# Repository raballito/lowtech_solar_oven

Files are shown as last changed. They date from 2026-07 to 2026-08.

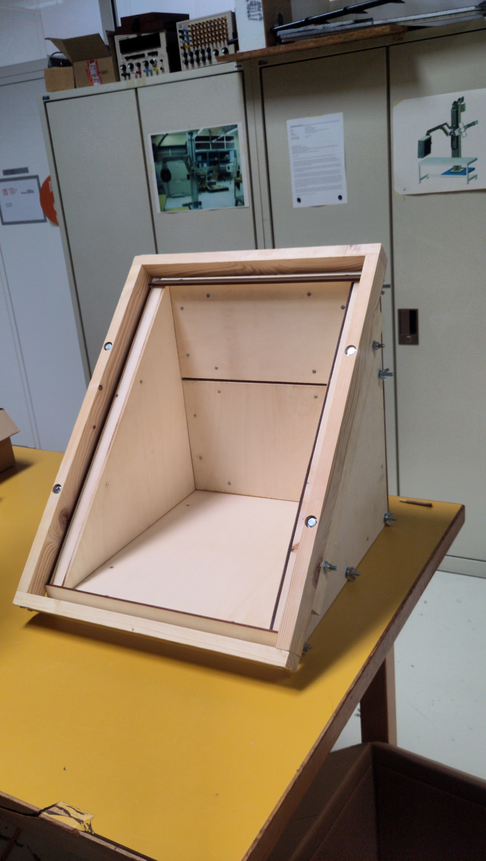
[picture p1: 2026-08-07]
IMG/IMG_20260701_142943_NR.jpg

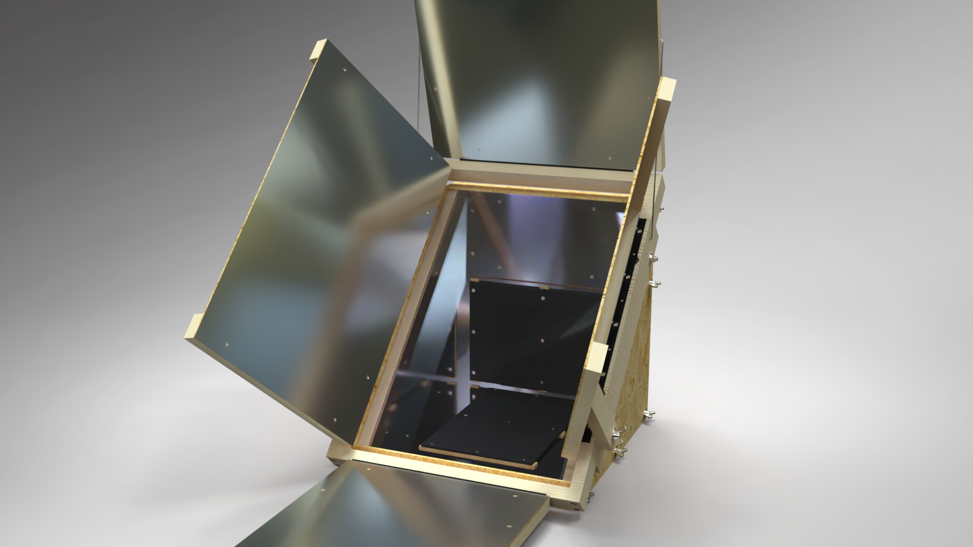
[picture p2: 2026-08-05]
Four Solaire Ouvert.png

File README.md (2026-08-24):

# Four solaire Low-tech

Ce répertoire contient tous les éléments afin de construire un four solaire low-tech DIY démontable.

Four Solaire Fermé

Ce four a été réalisé par Q.Raball dans le cadres du stage WINS 2026 de la HEIG-VD : https://heig-vd.ch/campus/ateliers-jeunes/wins/

Il a grandement été inspiré par le four Atominique dont la documentation, les plans, les instructions sont disponibles ici : https://four-atominique.retzien.fr/index.php?title=Accueil

Il reprend aussi certain élément intéressant du séchoir solaire de Mélanie Thomas disponible ici : [https://wiki.lowtechlab.org/wiki/S%C3%A9choir_solaire_d%C3%A9montable](https://wikifab.org/wiki/S%C3%A9choir_solaire_compact)

## Structure du Git
### Le dossier "CAO" contient les éléments suivants :
- Un fichier de prévisualisation du four au format EDrawings avec les deux configuration du four (ouvert/fermé). Le format EDrawings est très simple d'utilisation et pratique. Il est possible de bouger l'assemblage, de cacher certaines parties, de mettre en transparence certain éléments et permet de garder les configurations, les textures, la nomenclature, etc... Le logiciel est disponible gratuitement ici : https://www.edrawingsviewer.com/download-edrawings


- Dossier "STEP" avec toutes les pièces en 3D, au format STEP, ainsi que les fichiers d'assemblages final (Assemblage_Four_Deflecteur.STEP).
- Dossier "Solidworks" avec toutes les pièces en 3D, au format solidworks 2024, ainsi que les fichiers d'assemblages final (Assemblage_Four_Deflecteur.SLDASM).

### Le dossier "Docs" contient les éléments suivants : 
- Un dossier "BOM" avec la liste du matériel nécessaire à la fabrication (BOM), avec dimensions, quantités, prix, lien d'achat. Le classeur contient trois onglets: Le BOM par sous-assemblage, le BOM par type de composant et une liste de choix de miroirs pour l'intérieur et l'extérieur du four au cas où ceux dans les les autres ne sont plus disponibles à l'achat.


- Un dossier "Retour d'expérience" avec les différents problèmes rencontrés et les solutions mises en place.
- Un dossier "Choix des matériaux" avec les différents matériaux utilisés, les raisons des choix et les alternatives possibles.

### Le dossier "Plan" contient les éléments suivants : 
- Dossier "DXF" avec les fichiers de découpes afin de découper les panneaux de bois par technologie laser.
- Dossier "PDF" avec tous les plans des pièces avec assemblage, usinages et cotes


- Dossier "Solidworks" avec tous les fichiers de mises en plan au format Solidworks 2024

### Le dossier "Vids" contient les éléments suivants : 
- Les animations de montages pour les différents sous-assemblages du fours. Ne pas hésiter à ralentir la vidéo ou à mettre sur pause pour améliorer la compréhension.
Boite-ezgif com-video-to-gif-converter

## Liste des outils nécessaire à la fabrication et au montage
### Fabrication
- De quoi mesurer (règle, mètre déroulant) et écrire sur le bois (crayon de préférence).
- Une équerre à chapeau (DIN 875-2 idéalement), pour tracer des perpendiculaires et servir de guide à la découpe.
- Des serre-joints, ou pinces de bridage afin de maintenir deux éléments ensemble. Cela peut être pratique pour les positions des perçages si le plan n'est pas respecté à la lettre.
- Une scie (sauteuse) pour la découpe des tasseaux de bois et des tôles / miroirs. Un cutter peut être utile aussi.
- Une perceuse à colonne avec un jeu de mèches à bois. La plupart des trous sont Ø5, Ø9 ou Ø10. Les pré-trous pour les vis peuvent être fait avec une mèche de Ø2 (à adapter en fonction de la dureté du bois et de la taille des vis utilisées).
- Des mèches pour lamage droit / mèche à façonner / mèche-fraise plate de Ø20 ou Ø21 pour les têtes de vis et une de Ø13 ou Ø14 pour les écrous.
- Une mèche à tôle de Ø5 pour percer la tôle en acier. Une mèche standard peut se coincer et peut être dangereux.
- Eventuellement, une petite perceuse électroportative sur batterie peut être utile.

### Montage
- Tournevis / visseuse avec embout adapté aux vis utilisées.
- Clé à fourche taille 13 et clé à douille taille 13 pour la fixation des vis 6 pans dans les tasseaux.
- Des limes plates et rondes pour adapter les jeux entre les pièces et la taille des trous si nécessaire. Eventuellement une ponceuse peut être aussi utile.
- Des serre-joints, ou pinces de bridage afin de maintenir deux éléments ensemble. Cela peut être pratique pour assembler les tasseaux aux panneaux de bois.

Four Solaire Ouvert (3)

## Améliorations possibles / recommandées
- Afin de protéger les miroirs des rayures lorsqu'on les replies, les miroirs sont tapissés derrière la surface réfléchissante d'un tissus fin, et les charnières sont recouvertes d'un feutre. Des patins en caoutchouc ont été ajoutés sur le bas du cadre pour éviter que le grand miroir du dessus repose sur le bois directement.
- Remplacer les tringles en acier par un dispositif plus rigide. Au vu de la longueur des tringles prévues, elles ont tendances à fléchir. Pour éviter le fléchissement, il faut soit agrandir le diamètre de la tringle, soit raccourcir celle-ci. Sinon, il est aussi possible de changer le dispositif de réglage par une plaque en bois avec des secteurs. Un exemple de système de réglage est proposé à la fois dans les fichiers de découpes, les plans. Ne pas hésiter à adapter les formes, le nombre de trous à convenance.
- Il peut être judicieux d'ajouter un tablard sur le dessus afin de poser le plat à cuisiner pour ouvrir la porte. Par contre, si le dispositif est fixe, il devient plus compliqué de stocker le four à plat une fois démonté. Il est aussi plus compliqué de faire une four de protection adaptée avec un tel élément qui dépasse.
- Comme le four est lourd et encombrant, il peut être bien de le monter sur un chariot ou de rajouter des pieds à roulettes pour le déplacer. Un module supplémentaire sera inclus pour la version 2 du four.
- Le choix des matériaux pour les miroirs dépend fortement du budget à disposition. Plusieurs solutions sont possibles: plaques inox miroirs (lourd), panneaux de bois recouvert d'un film miroir (moins durable, plus simple), miroirs en plastiques (peut jaunir avec le temps), panneau Alucobond/Dibond (très cher et impossible d'avoir en petite quantité).
- Afin d'éviter au déflecteurs latéraux de se refermer avec le vent, il peut être judicieux de percer le cadre du déflecteur avec le support latéral servant à maintenir l'angle afin d'y mettre un clou. Cela permettra de bloquer la rotation du déflecteur.

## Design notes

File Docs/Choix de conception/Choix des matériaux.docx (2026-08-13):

# Choix des matériaux

## Enceinte du four

### Cahier des charges

Pour l'enceinte du four, les critères retenus sont :

- Absence de toxicité ;
- Résistance à la chaleur, avec une température de fonctionnement visée jusqu'à 180 °C ;
- Si possible, biocompatibilité / compatibilité alimentaire ;
- Faible masse ;
- Bonne durabilité ;
- Matériaux facilement disponibles et reproductibles ;
- Possibilité de remplacement ou de réparation.

### Structure en bois

Le contreplaqué de peuplier, notamment en 6 mm, a été envisagé pour les panneaux intérieurs et extérieurs de l'enceinte.

Ses avantages sont :

- Faible masse ;
- Bonne rigidité ;
- Coût raisonnable ;
- Disponibilité relativement importante, y compris en grande surface ;
- Bonne usinabilité et bonne découpe laser ;
- Matériau simple à remplacer ;
- Cohérent avec une démarche lowtech et open source.

Le point de vigilance principal est la colle utilisée dans le contreplaqué. Pour les éléments proches de l'intérieur chaud du four, il faut privilégier un panneau dont le fabricant peut fournir des informations sur les émissions, les colles et l'usage prévu. Le fait qu'un bois soit naturel ne signifie pas nécessairement que le panneau contreplaqué est automatiquement adapté à un environnement alimentaire ou à 180 °C.

Les panneaux ont été commandés en 800x500mm simplement car il s’agit de la taille maximum à disposition pour la machine de découpe laser disponible à l’école (Trotec Speedy 360).

Les tasseaux sont en sapin et de dimensions 24x48 et d’une longueur de 2m. Ces dimensions ont été choisies pour des raisons pratiques : facilement disponible dans n’importe quel magasin de bricolage, bonne rigidité globale et disponible en paquet de 10 (le nombre nécessaire pour la fabrication du four et des déflecteurs). 2m semble être le bon compromis, permettant un transport aisé en véhicule.

Aussi, aucune peinture doit être utilisé proche des aliments. L’intérieur est donc laissé brut. L’extérieur peut être discuté, mais comme le four est rangé en intérieur, l’extérieur sera laissé brut aussi.

### Isolation

Une isolation de l'ordre de 20mm a été envisagée. Les tasseaux utilisés faisant 24mm d’épaisseur, la différence de hauteur est compensée par l’ajout d’une plaque de 4mm coupé à la taille voulue à l’aide de la découpeuse laser.

Ses avantages sont :

- Faible conductivité thermique ;
- Bonne tenue en température ;
- Absence d'émissions indésirables lorsqu'il est chauffé ;
- Supporte l’humidité ;
- Faible masse ;
- Bonne disponibilité dans les commerces ;
- Possibilité de remplacement.

Le liège expansé constitue une piste particulièrement cohérente avec la philosophie du projet : matériau relativement accessible, biosourcé, léger et intéressant thermiquement. Il faut néanmoins vérifier la température maximale admissible du produit précis choisi et la nature éventuelle des liants.

Aussi, les panneaux de lièges se retrouvent dans la fabrication de fours solaires chez plein de fournisseurs (i.e SolarBrother).

### Revêtement intérieur réfléchissant

Le papier aluminium alimentaire a été utilisé dans le prototype, mais plusieurs limites ont été identifiées :

- Surface froissée ;
- Réflexion moins bonne qu'une surface métallique bien plane ;
- Fragilité ;
- Dégradation lors des manipulations ;
- Difficulté à le positionner et le faire tenir en place.

Une tôle d'aluminium mince (~0,8 mm) trouvée en magasin de bricolage constitue une solution beaucoup plus intéressante pour tapisser l'intérieur.

Ses avantages sont :

- Légère ;
- Assez rigide ;
- Facilement disponible ;
- Facile à nettoyer ;
- Meilleure planéité que le papier aluminium ;
- Facilement remplaçable.

Par contre, il faut faire attention à ne pas le rayer car il est compliqué de lui faire retrouver sa brillance. Après essais au papier de verre (jusqu’à P4000), l’aluminium est devenu mat. Il faut donc chercher à minimiser les rayures, mais sans pour autant s’acharner dessus.

## Déflecteurs extérieurs

### Cahier des charges

- Pas en contact avec les aliments ;
- Exposition directe au rayonnement solaire ;
- Bonne résistance aux UV ;
- Bonne résistance aux variations de température ;
- Bonne légereté ;
- Bonne planéité ;
- Bonne rigidité pour conserver leur géométrie ;

### Dibond / Alucobond miroir

Le Dibond miroir a été étudié comme solution très robuste.

Ses avantages sont :

- Excellente planéité ;
- Bonne rigidité ;
- Faible masse par rapport à un miroir en verre ;
- Bonne résistance extérieure ;
- Surface réfléchissante durable.

Mais le principal problème est le coût, de l'ordre de 100 CHF/m² dans les fournisseurs trouvés.

Pour un projet dont l'objectif est la reproductibilité et l'accessibilité, ce prix est difficile à justifier.

### Inox poli

L'acier inoxydable poli a également été envisagé.

Il présente une excellente durabilité et une très bonne résistance aux UV et aux intempéries, mais la masse devient rédhibitoire : pour les dimensions envisagées, on arrivait à environ 10 kg supplémentaires, sans parler du coût assez élevé de l’inox.

Cette solution a été écarté pour rester cohérent avec l’objectif d’être léger et peu cher.

### Contreplaqué + film miroir

C'est finalement une solution particulièrement intéressante :

Le contreplaqué fournit la rigidité mécanique et le film fournit la fonction optique.

Ses avantages sont :

- Très faible coût ;
- Faible masse globale;
- Fabrication simple ;
- Facilement réparable ;
- Matériau disponible localement ;
- Possibilité de remplacer uniquement la surface réfléchissante.

Le principal défaut est évidemment la durée de vie du film :

- UV ;
- Rayures ;
- Plis ;
- Résistance à l’humidité faible ;

Mais cela ne constitue pas nécessairement un problème de conception.

Un film qui doit être remplacé tous les 3–4 ans n'est pas nécessairement moins durable qu'un panneau miroir très coûteux qui dure beaucoup plus longtemps.

Si le panneau support reste intact et que seul le film est remplacé, on évite de jeter toute la pièce.

L'idéal est donc de concevoir le film pour être facilement démontable et remplaçable, plutôt que de le considérer comme une partie permanente du panneau.

### Miroir en polystyrène 2 mm

Des panneaux miroir en polystyrène de 2 mm ont été trouvés en magasin de bricolages

C'est une piste intéressante pour les déflecteurs car ils sont :

- Très légers ;
- Rigides ;
- Réfléchissants ;
- Relativement économiques ;
- Faciles à découper.

Par contre, les principaux points de vigilance sont :

- Sensibilité aux rayures ;
- Déformation thermique ;
- Vieillissement aux UV ;
- Tenue du matériau lorsqu'il est exposé directement au Soleil.

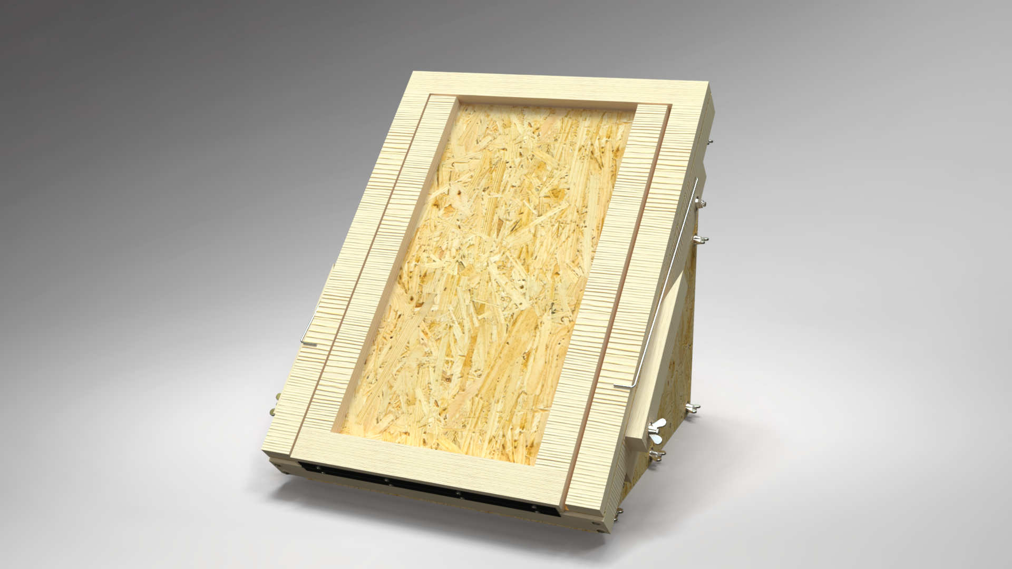
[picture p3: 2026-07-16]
Four Solaire Fermé.png

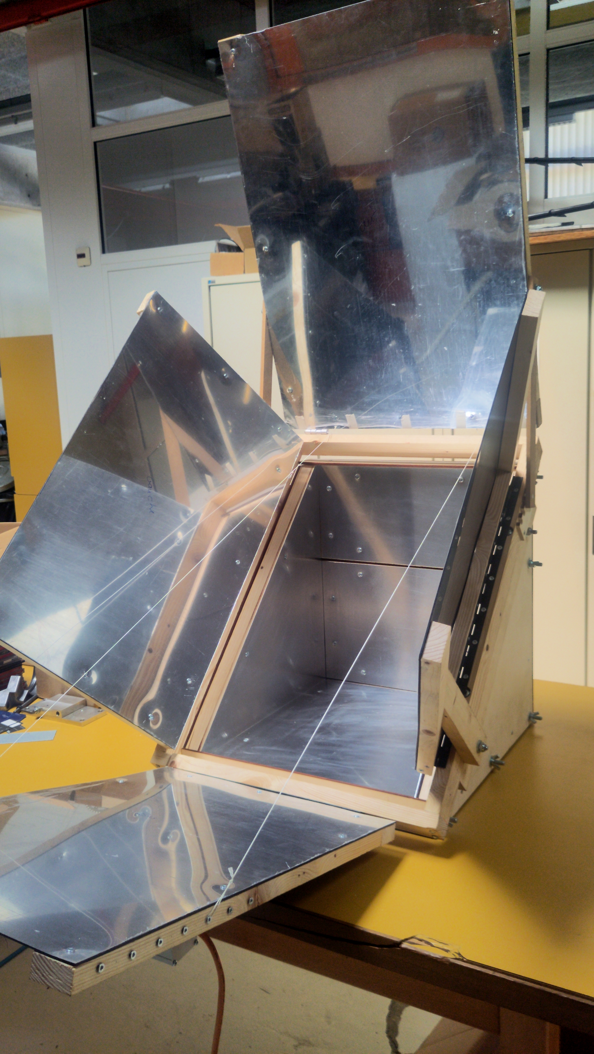
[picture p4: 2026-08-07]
IMG/IMG_20260807_123827_NR.jpg

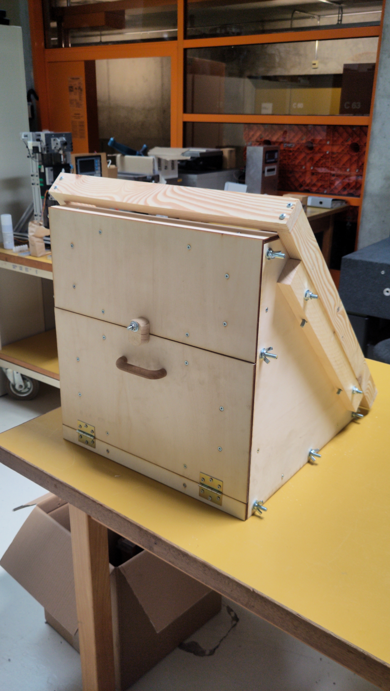
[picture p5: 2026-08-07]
IMG/IMG_20260701_143000_NR.jpg

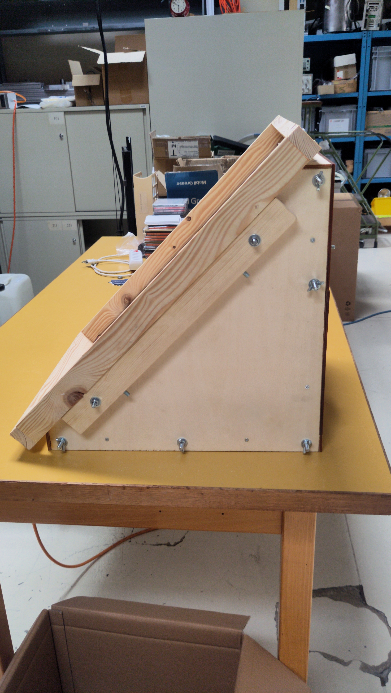
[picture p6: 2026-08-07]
IMG/IMG_20260701_143033_NR.jpg

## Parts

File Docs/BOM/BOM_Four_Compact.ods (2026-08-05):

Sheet: BOM_par_assamblage
No. ARTICLE | NUMERO DE PIECE | DESCRIPTION | Dimensions brutes | QTE | Prix Unitaire [CHF] | Prix Tot [CHF] | Opérations supplémentaires | Lien achat
1 | Assemblage_Four_Solaire | Assemblage Partie Boite | 510x505x516 | 1 | 194,52 |  | Assembler les panneaux à l'aide des écrous à oreilles
1.1 | Assemblage_Dessous | Assemblage de la partie du dessous | 500x468x55 | 1 | 44,34 | 44,34
1.1.1 | Base_Dessous | Plaque de base dessous | 500x400x6 | 2 | 5,40 | 10,80 | Trous pour passage de vis Ø5 (deux par côtés) | Panneau contreplaqué en peuplier Oecoplan A/B 6 mm Acheter chez JUMBO (https://www.jumbo.ch/fr/construction-renovation/bois/decoupe-du-bois/panneaux-contreplaques/panneau-contreplaque-en-peuplier-oecoplan-ab-6-mm/p/4706102) | 10.8CHF/panneau | 27CHF/m2
1.1.2 | Tasseau_304 | Tasseau dessous court | 304x48x24 | 4 | 0,36 | 1,46 |  | Tasseau brut Oecoplan | 2000 x 24 x 48 mm Acheter chez JUMBO (https://www.jumbo.ch/fr/construction-renovation/bois/bois-de-construction-bois-profile/lattes-de-toit/tasseau-brut-oecoplan--2000-x-24-x-48-mm/p/3851678)
1.1.3 | Tasseau_500_Dessous | Tasseau dessous long | 500x48x24 | 2 | 0,60 | 1,20 | Lamages de chaque côté Ø20 & Ø14 et trous passage de vis Ø8 | Tasseau brut Oecoplan | 2000 x 24 x 48 mm Acheter chez JUMBO (https://www.jumbo.ch/fr/construction-renovation/bois/bois-de-construction-bois-profile/lattes-de-toit/tasseau-brut-oecoplan--2000-x-24-x-48-mm/p/3851678) | 1.2CHF/m
1.1.4 | DIN EN 24015 - M8 x 90 | Vis tête hexagonale DIN EN 24015 - M8 x 90 | M8x90 | 6 | 1,17 | 7,00 | A fixer sur les tasseaux long | Ayce Vis à Tête Hexagonale | M8 Acheter chez JUMBO (https://www.jumbo.ch/fr/gros-outillage-atelier/petite-quincaillerie/vis/vis-a-metaux/ayce-vis-a-tete-hexagonale--m8/p/6930456) | 7CHF/6pièce
1.1.5 | DIN 315-M8-GT-C-C | Écrou à oreilles DIN 315 - M8 | M8 | 6 | 1,20 | 7,20 | Pour fixation des parois | Ayce Écrou à ailettes | M8 Acheter chez JUMBO (https://www.jumbo.ch/fr/gros-outillage-atelier/petite-quincaillerie/rondelles-plates-ecrous-gefundene-terminologie-eintraege4/ayce-ecrou-a-ailettes--m8/p/6930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) | 6CHF/5pièce
1.1.6 | Isolation_Dessous | Isolation en liège expensé | 303x102x20 | 3 | 0,80 | 2,41 | Idéalement, épaisseur de 24mm, sinon compléter avec panneau en bois de 4mm | Liège - Meige Matériaux (https://meige.ch/produits/isolation-et-etancheite/liege) | 26CHF/m2
1.1.7 | Cale_Plaque_Acier | Cale pour plaque acier | 250x20x4 | 3 | 0,11 | 0,32 | Trous de passage de vis Ø5 pour fixation sur dessous | Panneau contreplaqué en peuplier Oecoplan A/B 6 mm Acheter chez JUMBO (https://www.jumbo.ch/fr/construction-renovation/bois/decoupe-du-bois/panneaux-contreplaques/panneau-contreplaque-en-peuplier-oecoplan-ab-6-mm/p/4706102)
1.1.8 | Plaque_Acier | Plaque acier | 360x240x5 | 1 |  |  | A repeindre en noir avec peinture compatible avec la nourriture
1.1.9 | Planche_Fermeture | Planche de maintient de la vitre | 472x55x6 | 1 | 0,70 | 0,70 | Trous pour passage de vis Ø5 (3 pour fixation sur tasseau 304) | Panneau contreplaqué en peuplier Oecoplan A/B 6 mm Acheter chez JUMBO (https://www.jumbo.ch/fr/construction-renovation/bois/decoupe-du-bois/panneaux-contreplaques/panneau-contreplaque-en-peuplier-oecoplan-ab-6-mm/p/4706102)
1.1.10 | Planche_Derrière | Planche de maintient des charnière | 472x34x6 | 1 | 0,43 | 0,43 | Trous pour passage de vis Ø5 (2 pour fixation sur tasseau 304 + charnière (TBD)) | Panneau contreplaqué en peuplier Oecoplan A/B 6 mm Acheter chez JUMBO (https://www.jumbo.ch/fr/construction-renovation/bois/decoupe-du-bois/panneaux-contreplaques/panneau-contreplaque-en-peuplier-oecoplan-ab-6-mm/p/4706102)
1.1.11 | Charnière50x50 | Charnière Acier Noir | 50x50 | 2 | 2,25 | 4,50 | A fixer sur "Planche_Derrière" et à la porte (2x) | Hettich charnière de meuble | acier | noir | 50 mm (https://www.jumbo.ch/fr/gros-outillage-atelier/ferrures-accessoires/ferrures/charnieres-vivaneaux/hettich-charniere-de-meuble--acier--noir--50-mm/p/7491098) | 5.5CHF/2pièces
1.1.12 | Hexagon Nut ISO 4034 - M8 - C | Écrou hexagonal ISO 4034 - M8 | M8 | 6 | 0,30 | 1,80 |  | Ayce Écrou Hexagonal | M8 Acheter chez JUMBO (https://www.jumbo.ch/fr/gros-outillage-atelier/petite-quincaillerie/rondelles-plates-ecrous-gefundene-terminologie-eintraege4/ayce-ecrou-hexagonal--m8/p/6930078) | 3CHF/10pièce
1.1.13 | Complément_isolation_dessous | Panneau complémentaire à l'isolation | 303x102x4 | 3 | 0,65 | 1,95 | Laisser du jeu pour qu'elles soient facilement positionnable sur l'isolation | Panneau contreplaqué en peuplier Oecoplan A/B 4 mm Acheter chez JUMBO (https://www.jumbo.ch/fr/construction-renovation/bois/decoupe-du-bois/panneaux-contreplaques/panneau-contreplaque-en-peuplier-oecoplan-ab-4-mm/p/4706098) | 8.4CHF/panneau | 21CHF/m2
1.1.14 | Washer ISO 7093 - 8 | Rondelle ISO 7093 - 8 | Ø24x2 | 6 | 0,12 | 0,72
1.1.15 | Vis à bois Ø4,5x16 | Vis pour fixation des face devant et derrnière | Ø4.5x16 | 5 | 0,09 | 0,43 | Les vis doivent être plus courte pour ne pas poser problème | Ayce Vis à bois universelle à tête fraisée | 4 × 16 mm Acheter chez JUMBO (https://www.jumbo.ch/fr/gros-outillage-atelier/petite-quincaillerie/vis/vis-a-bois/ayce-vis-a-bois-universelle-a-tete-fraisee--4--16-mm/p/6928458) | 6CHF/70Pièces
1.1.16 | Vis à bois Ø4,5x20 | Vis pour fixations des panneaux bois | Ø4.5x20 | 20 | 0,12 | 2,40 | Attention à les décaler dessous-dessus | Ayce Vis à bois universelle à tête fraisée | 20 × 4.5 mm Acheter chez JUMBO (https://www.jumbo.ch/fr/gros-outillage-atelier/petite-quincaillerie/vis/vis-a-bois/ayce-vis-a-bois-universelle-a-tete-fraisee--20--45-mm/p/6929252) | 6CHF/50pièces
1.1.17 | Vis à bois Ø4,5x30 | Vis pour fixation de la plaque acier | Ø4.5x30 | 9 | 0,11 | 1,03 | Pour la fixation de la plaque acier. | Ayce Vis à bois universelle à tête fraisée | 4.5 × 30 mm Acheter chez JUMBO (https://www.jumbo.ch/fr/gros-outillage-atelier/petite-quincaillerie/vis/vis-a-bois/ayce-vis-a-bois-universelle-a-tete-fraisee--45--30-mm/p/6930359) | 8CHF/70pièces
1.2 | Assemblage_Parois | Assemblage des parois | 500x500x58 | 2 | 17,63 | 35,27 | Parois symétriques. Attention au montage. Grande plaques et tasseau suppl. à l'extérieur
1.2.1 | Base_Parois | Plaque de base parois | 500x500x6 | 2 | 3,38 | 6,75 | Attention, deux versions différentes. La grande plaque à l'extérieur avec trous suppl. sur la diagonale | Panneau contreplaqué en peuplier Oecoplan A/B 6 mm Acheter chez JUMBO (https://www.jumbo.ch/fr/construction-renovation/bois/decoupe-du-bois/panneaux-contreplaques/panneau-contreplaque-en-peuplier-oecoplan-ab-6-mm/p/4706102)
1.2.2 | Tasseau_500_Parois | Tasseau horizontal parois | 500x48x24 | 1 | 0,60 | 0,60 | Trous pour passage des vis M8 de fixation avec le dessous | Tasseau brut Oecoplan | 2000 x 24 x 48 mm Acheter chez JUMBO (https://www.jumbo.ch/fr/construction-renovation/bois/bois-de-construction-bois-profile/lattes-de-toit/tasseau-brut-oecoplan--2000-x-24-x-48-mm/p/3851678)
1.2.3 | Tasseau_Parois_Biais | Tasseau de biais parois | 639x48x24 | 1 | 0,77 | 0,77 | Couper les extrémités à 45°. Deux trous de passages de vis M8. Intérieur avec lamages suppl. | Tasseau brut Oecoplan | 2000 x 24 x 48 mm Acheter chez JUMBO (https://www.jumbo.ch/fr/construction-renovation/bois/bois-de-construction-bois-profile/lattes-de-toit/tasseau-brut-oecoplan--2000-x-24-x-48-mm/p/3851678)
1.2.4 | Tasseau_Parois_Ext | Tasseau Extérieur pour support déflecteurs | 540x48x24 | 1 | 0,65 | 0,65 | Deux trous Ø10 pour fixation du cadre du déflecteur.
1.2.5 | Tasseau_452_Parois | Tasseau verticale parois | 452x48x24 | 1 | 0,54 | 0,54 | Trous de passage des vis M8 de fixation avec le fond. Attention à la position des trous. | Tasseau brut Oecoplan | 2000 x 24 x 48 mm Acheter chez JUMBO (https://www.jumbo.ch/fr/construction-renovation/bois/bois-de-construction-bois-profile/lattes-de-toit/tasseau-brut-oecoplan--2000-x-24-x-48-mm/p/3851678)
1.2.6 | Isolation_Parois_Verticale | Isolation en liège expensé | 383x383x20 | 1 | 1,91 | 1,91 | Idéalement, épaisseur de 24mm, sinon compléter avec panneau en bois de 4mm. Couper le carré à 45° | Liège - Meige Matériaux (https://meige.ch/produits/isolation-et-etancheite/liege)
1.2.7 | Complément_isolation_parois | Panneau complémentaire à l'isolation | 383x383x4 | 1 | 1,54 | 1,54 | Laisser du jeu pour qu'elles soient facilement positionnable sur l'isolation | Panneau contreplaqué en peuplier Oecoplan A/B 4 mm Acheter chez JUMBO (https://www.jumbo.ch/fr/construction-renovation/bois/decoupe-du-bois/panneaux-contreplaques/panneau-contreplaque-en-peuplier-oecoplan-ab-4-mm/p/4706098)
1.2.8 | DIN EN 24015 - M8 x 60 | Vis tête hexagonale DIN EN 24015 - M8 x 60 | M8x60 | 2 | 1,00 | 2,00 | A fixer sur le tasseau de biais intérieur | Ayce Vis à Tête Hexagonale | M8 Acheter chez JUMBO (https://www.jumbo.ch/fr/gros-outillage-atelier/petite-quincaillerie/vis/vis-a-metaux/ayce-vis-a-tete-hexagonale--m8/p/6930585) | 6CHF/6pièces
1.2.9 | Washer ISO 7093 - 8 | Rondelle ISO 7093 - 8 | Ø24x2 | 2 | 0,12 | 0,24 |  | Ayce Rondelle | M8 Acheter chez JUMBO (https://www.jumbo.ch/fr/gros-outillage-atelier/petite-quincaillerie/rondelles-plates-ecrous-gefundene-terminologie-eintraege4/ayce-rondelle--m8/p/6928510) | 6CHF/50pièces
1.2.10 | ISO - 7040 - M8 - C | Écrou autofreiné hexagonal ISO 7040 - M8 | M8 | 2 | 0,60 | 1,20 | Pour fixation du tasseau extérieur sur parois. | Ayce Écrou de sécurité | SW13 Acheter chez JUMBO (https://www.jumbo.ch/fr/gros-outillage-atelier/petite-quincaillerie/rondelles-plates-ecrous-gefundene-terminologie-eintraege4/ayce-ecrou-de-securite--sw13/p/6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) | 6CHF/10pièces
1.2.11 | Vis à bois Ø4,5x20 | Vis pour fixations des panneaux bois | Ø4.5x20 | 12 | 0,12 | 1,44 | Attention à les décaler dessous-dessus. | Vis universelle à tête fraisée | 4.5 × 20 mm Acheter chez JUMBO (https://www.jumbo.ch/fr/gros-outillage-atelier/petite-quincaillerie/vis/vis-a-bois/vis-universelle-a-tete-fraisee--45--20-mm/p/6934638)
No. ARTICLE | NUMERO DE PIECE | DESCRIPTION | Dimensions brutes | QTE | Prix Unitaire [CHF] | Prix Tot [CHF] | Opérations supplémentaires | Lien achat
1.3 | Assemblage_Fond | Assemblage du fond | 472x205x60 | 1 | 25,71 | 25,71 | Attention au sens haut-bas.
1.3.1 | Base_Fond | Plaque de base du fond | 400x200x6 | 2 | 2,16 | 4,32 | Trous pour passage de vis Ø5 (deux par côtés) + 1 trou Ø9 pour vis de verrouillage de la porte. | Panneau contreplaqué en peuplier Oecoplan A/B 6 mm Acheter chez JUMBO (https://www.jumbo.ch/fr/construction-renovation/bois/decoupe-du-bois/panneaux-contreplaques/panneau-contreplaque-en-peuplier-oecoplan-ab-6-mm/p/4706102)
1.3.2 | Tasseau_200_Fond | Tasseau verticale fond | 200x48x24 | 2 | 0,24 | 0,48 | Lamages de chaque côté Ø20 & Ø14 et trous passage de vis Ø8 | Tasseau brut Oecoplan | 2000 x 24 x 48 mm Acheter chez JUMBO (https://www.jumbo.ch/fr/construction-renovation/bois/bois-de-construction-bois-profile/lattes-de-toit/tasseau-brut-oecoplan--2000-x-24-x-48-mm/p/3851678)
1.3.3 | Tasseau_304_Fond | Tasseau horizontal fond | 304x48x24 | 2 | 0,36 | 0,73 | Sur celui du bas, ajouter un trou de passage de vis Ø8 et lamage Ø14 | Tasseau brut Oecoplan | 2000 x 24 x 48 mm Acheter chez JUMBO (https://www.jumbo.ch/fr/construction-renovation/bois/bois-de-construction-bois-profile/lattes-de-toit/tasseau-brut-oecoplan--2000-x-24-x-48-mm/p/3851678)
1.3.4 | DIN EN 24015 - M8 x 90 | Vis tête hexagonale DIN EN 24015 - M8 x 90 | M8x90 | 4 | 1,17 | 4,67 |  | Ayce Vis à Tête Hexagonale | M8 Acheter chez JUMBO (https://www.jumbo.ch/fr/gros-outillage-atelier/petite-quincaillerie/vis/vis-a-metaux/ayce-vis-a-tete-hexagonale--m8/p/6930456)
1.3.5 | DIN 315-M8-GT-C-C | Écrou à oreilles DIN 315 - M8 | M8 | 4 | 1,20 | 4,80 | Pour fixation des parois | Ayce Écrou à ailettes | M8 Acheter chez JUMBO (https://www.jumbo.ch/fr/gros-outillage-atelier/petite-quincaillerie/rondelles-plates-ecrous-gefundene-terminologie-eintraege4/ayce-ecrou-a-ailettes--m8/p/6930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)
1.3.6 | Isolation_Fond | Isolation en liège expensé | 303x102x20 | 1 | 0,80 | 0,80 | Idéalement, épaisseur de 24mm, sinon compléter avec panneau en bois de 4mm | Liège - Meige Matériaux (https://meige.ch/produits/isolation-et-etancheite/liege)
1.3.7 | Planche_Fond_Grande | Planche Derrière Grande | 472x200x6 | 1 | 2,55 | 2,55 | Trous pour passage de vis Ø5 (deux par côtés) + 1 trou Ø9 pour vis de verrouillage de la porte. | Panneau contreplaqué en peuplier Oecoplan A/B 6 mm Acheter chez JUMBO (https://www.jumbo.ch/fr/construction-renovation/bois/decoupe-du-bois/panneaux-contreplaques/panneau-contreplaque-en-peuplier-oecoplan-ab-6-mm/p/4706102)
1.3.8 | Fixation_Porte | Système de fermeture de la porte | 60x48x24 | 1 | 0,07 | 0,07 | Arrondir les angles et un trou de passage de vis Ø9 | Tasseau brut Oecoplan | 2000 x 24 x 48 mm Acheter chez JUMBO (https://www.jumbo.ch/fr/construction-renovation/bois/bois-de-construction-bois-profile/lattes-de-toit/tasseau-brut-oecoplan--2000-x-24-x-48-mm/p/3851678)
1.3.9 | Planche_Fermeture | Planche_Fermeture (468x55) | 472x55x6 | 1 | 0,70 | 0,70 | Trous pour passage de vis Ø5 (3 pour fixation sur tasseau 304 du haut) | Panneau contreplaqué en peuplier Oecoplan A/B 6 mm Acheter chez JUMBO (https://www.jumbo.ch/fr/construction-renovation/bois/decoupe-du-bois/panneaux-contreplaques/panneau-contreplaque-en-peuplier-oecoplan-ab-6-mm/p/4706102)
1.3.10 | Hexagon Nut ISO 4034 - M8 - C | Écrou hexagonal ISO 4034 - M8 | M8 | 4 | 0,30 | 1,20 |  | Ayce Écrou Hexagonal | M8 Acheter chez JUMBO (https://www.jumbo.ch/fr/gros-outillage-atelier/petite-quincaillerie/rondelles-plates-ecrous-gefundene-terminologie-eintraege4/ayce-ecrou-hexagonal--m8/p/6930078)
1.3.11 | Complément_isolation_fond | Panneau complémentaire à l'isolation | 303x102x4 | 1 | 0,65 | 0,65 | Laisser du jeu pour qu'elles soient facilement positionnable sur l'isolation | Panneau contreplaqué en peuplier Oecoplan A/B 4 mm Acheter chez JUMBO (https://www.jumbo.ch/fr/construction-renovation/bois/decoupe-du-bois/panneaux-contreplaques/panneau-contreplaque-en-peuplier-oecoplan-ab-4-mm/p/4706098)
1.3.12 | DIN EN 24015 - M8 x 60 | Vis tête hexagonale DIN EN 24015 - M8 x 60 | M8x60 | 1 | 1,00 | 1,00 | Pour fixation du tasseau de fermeture de la porte | Ayce Vis à Tête Hexagonale | M8 Acheter chez JUMBO (https://www.jumbo.ch/fr/gros-outillage-atelier/petite-quincaillerie/vis/vis-a-metaux/ayce-vis-a-tete-hexagonale--m8/p/6930585)
1.3.13 | Washer ISO 7093 - 8 | Rondelle ISO 7093 - 8 | Ø24x2 | 1 | 0,12 | 0,12 |  | Ayce Rondelle | M8 Acheter chez JUMBO (https://www.jumbo.ch/fr/gros-outillage-atelier/petite-quincaillerie/rondelles-plates-ecrous-gefundene-terminologie-eintraege4/ayce-rondelle--m8/p/6928510)
1.3.14 | DIN EN ISO 7040 - M8 - C | Écrou autofreiné hexagonal ISO 7040 - M8 | M8 | 1 | 0,60 | 0,60 |  | Ayce Écrou de sécurité | SW13 Acheter chez JUMBO (https://www.jumbo.ch/fr/gros-outillage-atelier/petite-quincaillerie/rondelles-plates-ecrous-gefundene-terminologie-eintraege4/ayce-ecrou-de-securite--sw13/p/6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)
1.3.15 | Washer ISO 7093 - 8 | Rondelle ISO 7093 - 8 | Ø24x2 | 4 | 0,12 | 0,48
1.3.16 | Vis à bois Ø4,5x16 | Vis pour fixation des face devant et derrnière | Ø4.5x16 | 3 | 0,09 | 0,26 | Les vis doivent être plus courte pour ne pas poser problème | Ayce Vis à bois universelle à tête fraisée | 4 × 16 mm Acheter chez JUMBO (https://www.jumbo.ch/fr/gros-outillage-atelier/petite-quincaillerie/vis/vis-a-bois/ayce-vis-a-bois-universelle-a-tete-fraisee--4--16-mm/p/6928458)
1.3.17 | Vis à bois Ø4,5x20 | Vis pour fixations des panneaux bois | Ø4.5x20 | 19 | 0,12 | 2,28 | Attention à les décaler dessous-dessus. | Vis universelle à tête fraisée | 4.5 × 20 mm Acheter chez JUMBO (https://www.jumbo.ch/fr/gros-outillage-atelier/petite-quincaillerie/vis/vis-a-bois/vis-universelle-a-tete-fraisee--45--20-mm/p/6934638)
1.4 | Assemblage_Porte | Assemblage de la porte | 472x270x50 | 1 | 22,20 | 22,20
1.4.1 | Planche_Porte_Derrière_Grande | Grande plaque de la porte | 472x270x6 | 1 | 3,44 | 3,44 | Trous pour passage de vis Ø5 (deux par côté + charnière (TBD)) | Panneau contreplaqué en peuplier Oecoplan A/B 6 mm Acheter chez JUMBO (https://www.jumbo.ch/fr/construction-renovation/bois/decoupe-du-bois/panneaux-contreplaques/panneau-contreplaque-en-peuplier-oecoplan-ab-6-mm/p/4706102)
1.4.2 | Base_Porte | Petites plaque de base de la porte | 400x260x6 | 2 | 2,81 | 5,62 | Trous pour passage de vis Ø5 (deux par côté + plaque acier (TBD)) | Panneau contreplaqué en peuplier Oecoplan A/B 6 mm Acheter chez JUMBO (https://www.jumbo.ch/fr/construction-renovation/bois/decoupe-du-bois/panneaux-contreplaques/panneau-contreplaque-en-peuplier-oecoplan-ab-6-mm/p/4706102)
1.4.3 | Tasseau_260 | Tasseau vertical porte | 260x48x24 | 2 | 0,31 | 0,62 |  | Tasseau brut Oecoplan | 2000 x 24 x 48 mm Acheter chez JUMBO (https://www.jumbo.ch/fr/construction-renovation/bois/bois-de-construction-bois-profile/lattes-de-toit/tasseau-brut-oecoplan--2000-x-24-x-48-mm/p/3851678)
1.4.4 | Tasseau_304 | Tasseau horizontal porte | 304x48x24 | 2 | 0,36 | 0,73 |  | Tasseau brut Oecoplan | 2000 x 24 x 48 mm Acheter chez JUMBO (https://www.jumbo.ch/fr/construction-renovation/bois/bois-de-construction-bois-profile/lattes-de-toit/tasseau-brut-oecoplan--2000-x-24-x-48-mm/p/3851678)
1.4.5 | Isolation_Porte | Isolation en liège expensé | 303x163x20 | 1 | 1,28 | 1,28 | Idéalement, épaisseur de 24mm, sinon compléter avec panneau en bois de 4mm | Liège - Meige Matériaux (https://meige.ch/produits/isolation-et-etancheite/liege)
1.4.6 | Complément_isolation_porte | Panneau complémentaire à l'isolation | 303x163x4 | 1 | 1,04 | 1,04 | Laisser du jeu pour qu'elles soient facilement positionnable sur l'isolation | Panneau contreplaqué en peuplier Oecoplan A/B 4 mm Acheter chez JUMBO (https://www.jumbo.ch/fr/construction-renovation/bois/decoupe-du-bois/panneaux-contreplaques/panneau-contreplaque-en-peuplier-oecoplan-ab-4-mm/p/4706098)
1.4.7 | Plaque_Acier | Plaque acier | 360x240x5 | 1 |  |  | Doit être percée et maintenue à la porte, séparée par les cales
1.4.8 | Cale_Plaque_Acier_Porte | Cale pour plaque acier | 250x20x4 | 3 | 0,11 | 0,32 | Trous de passage de vis Ø5 pour fixation sur porte | Panneau contreplaqué en peuplier Oecoplan A/B 4 mm Acheter chez JUMBO (https://www.jumbo.ch/fr/construction-renovation/bois/decoupe-du-bois/panneaux-contreplaques/panneau-contreplaque-en-peuplier-oecoplan-ab-4-mm/p/4706098)
1.4.9 | Poignée_Porte | Poignée en bois pour porte | 107*14*29 | 1 | 6,20 | 6,20 | TBD | Siro Poignée de meuble en Érable Brut | 107 × 14 × 29 mm Acheter chez JUMBO (https://www.jumbo.ch/fr/gros-outillage-atelier/ferrures-accessoires/ferrures/boutons-poignees/siro-poignee-de-meuble-en-erable-brut--107--14--29-mm/p/3444144) | 6.2CHF/pièce
1.4.10 | Vis à bois Ø4,5x20 | Vis pour fixations des panneaux bois | Ø4.5x20 | 16 | 0,12 | 1,92 | Attention à les décaler dessous-dessus. | Vis universelle à tête fraisée | 4.5 × 20 mm Acheter chez JUMBO (https://www.jumbo.ch/fr/gros-outillage-atelier/petite-quincaillerie/vis/vis-a-bois/vis-universelle-a-tete-fraisee--45--20-mm/p/6934638)
1.4.11 | Vis à bois Ø4,5x30 | Vis pour fixation de la plaque acier | Ø4.5x30 | 9 | 0,11 | 1,03 | Pour la fixation de la plaque acier. | Ayce Vis à bois universelle à tête fraisée | 4.5 × 30 mm Acheter chez JUMBO (https://www.jumbo.ch/fr/gros-outillage-atelier/petite-quincaillerie/vis/vis-a-bois/ayce-vis-a-bois-universelle-a-tete-fraisee--45--30-mm/p/6930359)
1.5 | Tôle aluminium fine | Tôle alu miroir pour intérieur du four | 600x1000x0.8 | 1 | 42,00 | 42,00 | A découper selon les plans | Alfer Tôle lisse en Aluminium | 1000 × 600 × 0.8 mm Acheter chez JUMBO (https://www.jumbo.ch/fr/gros-outillage-atelier/ferrures-accessoires/profils/profiles-en-aluminium/alfer-tole-lisse-en-aluminium--1000--600--08-mm/p/4151895)
1.6 | Vitre | Vitre 4mm | 631x458x4 | 1 | 25,00 | 25,00 | Ajuster le jeu entre la plaque du haut et la vitre avec un morceau de tissus / liège (max 1mm à compenser) | vitrerie en ligne (https://vitreenligne.ch/fr/verre-transparent-/441-verre-float-4-mm-clair-verre-float-4-mm-clair-accueil-chf-1400.html)
No. ARTICLE | NUMERO DE PIECE | DESCRIPTION | Dimensions brutes | QTE | Prix Unitaire [CHF] | Prix Tot [CHF] | Opérations supplémentaires | Lien achat
2 | Assemblage_Déflecteurs | Assemblage Partie Déflecteurs | 728x566x80 | 1 | 66,96
2.1 | Cadre déflecteurs | Cadre support déflecteurs | 728x566x48 | 1
2.1.1 | Tasseau_518 | Tasseau Cadre Déflecteurs Court | 518x48x24 | 2 | 0,62 | 1,24 | 2x2 trous Ø5 aux extrémités pour former le cadre du déflecteurs | Tasseau brut Oecoplan | 2000 x 24 x 48 mm Acheter chez JUMBO (https://www.jumbo.ch/fr/construction-renovation/bois/bois-de-construction-bois-profile/lattes-de-toit/tasseau-brut-oecoplan--2000-x-24-x-48-mm/p/3851678)
2.1.2 | Tasseau_680 | Tasseau Cadre Déflecteurs Long | 680x48x24 | 2 | 0,82 | 1,63 | Faire 2x2 prétrous Ø3,5 pour assemblage cadre du déflecteurs. Lamages pour vis M8 dessus dessous et coté int. | Tasseau brut Oecoplan | 2000 x 24 x 48 mm Acheter chez JUMBO (https://www.jumbo.ch/fr/construction-renovation/bois/bois-de-construction-bois-profile/lattes-de-toit/tasseau-brut-oecoplan--2000-x-24-x-48-mm/p/3851678)
2.1.3 | Vis à bois Ø4.5 x 50 | Vis à bois Ø4.5 x 50 | Ø4.5x50 | 8 | 0,18 | 1,44 | Pour fixation du cadre
2.2 | Assemblage_Déflecteur_Gauche | Panneau déflecteur gauche | 678x435x28 | 1 | 12,36 | 12,36
2.2.1 | Miroir_Déflecteur_Gauche | Panneau miroir gauche | 678x435x2 | 1 | 10,62 | 10,62 | Idéalement, prendre de l'aluminium poli miroir, ou panneau bois 4mm avec film miroir. | Miroir en Polystyrène | 100 × 200 cm Acheter chez JUMBO (https://www.jumbo.ch/fr/construction-renovation/verre-verre-synthetique/verre-synthetique/miroir-en-polystyrene--100--200-cm/p/3374634)
2.2.2 | Tasseau_435 | Tasseau déflecteur gauche court | 435x48x24 | 2 | 0,52 | 1,04 |  | Tasseau brut Oecoplan | 2000 x 24 x 48 mm Acheter chez JUMBO (https://www.jumbo.ch/fr/construction-renovation/bois/bois-de-construction-bois-profile/lattes-de-toit/tasseau-brut-oecoplan--2000-x-24-x-48-mm/p/3851678)
2.2.3 | Tasseau_582 | Tasseau déflecteur gauche long | 582x48x24 | 1 | 0,70 | 0,70 |  | Tasseau brut Oecoplan | 2000 x 24 x 48 mm Acheter chez JUMBO (https://www.jumbo.ch/fr/construction-renovation/bois/bois-de-construction-bois-profile/lattes-de-toit/tasseau-brut-oecoplan--2000-x-24-x-48-mm/p/3851678)
2.2.4 | Vis à bois Ø4.5 x 20 | Vis à bois Ø4.5 x 20 | Ø4.5x20 | 16 | 0,12 | 1,92
2.2.5 | Charnières | Charnières de piano | 600x32 | 1 | 4,00 | 4,00
2.3 | Assemblage_Déflecteur_Droite | Panneau déflecteur droite | 578x415x28 | 1 | 10,21 | 10,21
2.3.1 | Miroir_Déflecteur_Droite | Panneau miroir droite | 578x415x2 | 1 | 8,64 | 8,64 | Idéalement, prendre de l'aluminium poli miroir, ou panneau bois 4mm avec film miroir. | Miroir en Polystyrène | 100 × 200 cm Acheter chez JUMBO (https://www.jumbo.ch/fr/construction-renovation/verre-verre-synthetique/verre-synthetique/miroir-en-polystyrene--100--200-cm/p/3374634)
2.3.2 | Tasseau_415 | Tasseau déflecteur droite court | 415x48x24 | 2 | 0,50 | 1,00 |  | Tasseau brut Oecoplan | 2000 x 24 x 48 mm Acheter chez JUMBO (https://www.jumbo.ch/fr/construction-renovation/bois/bois-de-construction-bois-profile/lattes-de-toit/tasseau-brut-oecoplan--2000-x-24-x-48-mm/p/3851678)
2.3.3 | Tasseau_486 | Tasseau déflecteur droite long | 482x48x24 | 1 | 0,58 | 0,58 |  | Tasseau brut Oecoplan | 2000 x 24 x 48 mm Acheter chez JUMBO (https://www.jumbo.ch/fr/construction-renovation/bois/bois-de-construction-bois-profile/lattes-de-toit/tasseau-brut-oecoplan--2000-x-24-x-48-mm/p/3851678)
2.3.4 | Vis à bois Ø4.5 x 20 | Vis à bois Ø4.5 x 20 | Ø4.5x20 | 16 | 0,12 | 1,92
2.3.5 | Charnières | Charnières de piano | 500x32 | 1 | 4,00 | 4,00
2.4 | Assemblage_Déflecteur_Bas | Panneau déflecteur bas | 675x415x28 | 1 | 12,09 | 12,09
2.4.1 | Miroir_Déflecteur_Bas | Panneau miroir bas | 675x415x2 | 1 | 10,08 | 10,08 | Idéalement, prendre de l'aluminium poli miroir, ou panneau bois 4mm avec film miroir. | Miroir en Polystyrène | 100 × 200 cm Acheter chez JUMBO (https://www.jumbo.ch/fr/construction-renovation/verre-verre-synthetique/verre-synthetique/miroir-en-polystyrene--100--200-cm/p/3374634)
2.4.2 | Tasseau_415 | Tasseau déflecteur bas court | 415x48x24 | 1 | 0,50 | 0,50 |  | Tasseau brut Oecoplan | 2000 x 24 x 48 mm Acheter chez JUMBO (https://www.jumbo.ch/fr/construction-renovation/bois/bois-de-construction-bois-profile/lattes-de-toit/tasseau-brut-oecoplan--2000-x-24-x-48-mm/p/3851678)
2.4.3 | Tasseau_627 | Tasseau déflecteur bas long | 627x48x24 | 2 | 0,75 | 1,50 |  | Tasseau brut Oecoplan | 2000 x 24 x 48 mm Acheter chez JUMBO (https://www.jumbo.ch/fr/construction-renovation/bois/bois-de-construction-bois-profile/lattes-de-toit/tasseau-brut-oecoplan--2000-x-24-x-48-mm/p/3851678)
2.4.4 | Vis à bois Ø4.5 x 20 | Vis à bois Ø4.5 x 20 | Ø4.5x20 | 14 | 0,12 | 1,68
2.4.5 | Charnières | Charnières de piano | 400x32 | 1 | 4,00 | 4,00
2.5 | Assemblage_Déflecteur_Haut | Panneau déflecteur haut | 725x524x28 | 1 | 15,92 | 15,92
2.5.1 | Miroir_Déflecteur_Haut | Panneau miroir haut | 725x524x2 | 1 | 13,68 | 13,68 | Idéalement, prendre de l'aluminium poli miroir, ou panneau bois 4mm avec film miroir. | Miroir en Polystyrène | 100 × 200 cm Acheter chez JUMBO (https://www.jumbo.ch/fr/construction-renovation/verre-verre-synthetique/verre-synthetique/miroir-en-polystyrene--100--200-cm/p/3374634)
2.5.2 | Tasseau_524 | Tasseau déflecteur haut court | 518x48x24 | 1 | 0,62 | 0,62 |  | Tasseau brut Oecoplan | 2000 x 24 x 48 mm Acheter chez JUMBO (https://www.jumbo.ch/fr/construction-renovation/bois/bois-de-construction-bois-profile/lattes-de-toit/tasseau-brut-oecoplan--2000-x-24-x-48-mm/p/3851678)
2.5.3 | Tasseau_677 | Tasseau déflecteur haut long | 677x48x24 | 2 | 0,81 | 1,62 | Perçage pour tringle Ø3 tous les 15mm | Tasseau brut Oecoplan | 2000 x 24 x 48 mm Acheter chez JUMBO (https://www.jumbo.ch/fr/construction-renovation/bois/bois-de-construction-bois-profile/lattes-de-toit/tasseau-brut-oecoplan--2000-x-24-x-48-mm/p/3851678)
2.5.4 | Vis à bois Ø4.5 x 20 | Vis à bois Ø4.5 x 20 | Ø4.5x20 | 14 | 0,12 | 1,68
2.5.5 | Charnières | Charnières de piano | 400x32 | 1 | 4,00 | 4,00
2.6 | Divers | Quinquaillerie Diverse |  | 1 | 13,51 | 13,51
2.6.1 | DIN EN 24015 - M8 x 100 | Vis tête hexagonale DIN EN 24015 - M8 x 100 | M8x100 | 4 | 1,33 | 5,33 | Pour fixer le cadre sur le four | Ayce Vis à Tête Hexagonale | M8 Acheter chez JUMBO (https://www.jumbo.ch/fr/gros-outillage-atelier/petite-quincaillerie/vis/vis-a-metaux/ayce-vis-a-tete-hexagonale--m8/p/6930462) | 8CHF/6pièce
2.6.2 | ISO - 4034 - M8 - C | Écrou hexagonal ISO 4034 - M8 | M8 | 8 | 0,30 | 2,40 |  | Ayce Écrou Hexagonal | M8 Acheter chez JUMBO (https://www.jumbo.ch/fr/gros-outillage-atelier/petite-quincaillerie/rondelles-plates-ecrous-gefundene-terminologie-eintraege4/ayce-ecrou-hexagonal--m8/p/6930078)
2.6.3 | Washer ISO 7093 - 8 | Rondelle ISO 7093 - 8 | Ø24x2 | 6 | 0,12 | 0,72
2.6.4 | Tasseau_Support_Parois | Tasseau de support des parois latérales | 273x48x24 | 2 | 0,33 | 0,66 | Couper une extrémité à 108° | Tasseau brut Oecoplan | 2000 x 24 x 48 mm Acheter chez JUMBO (https://www.jumbo.ch/fr/construction-renovation/bois/bois-de-construction-bois-profile/lattes-de-toit/tasseau-brut-oecoplan--2000-x-24-x-48-mm/p/3851678)
2.6.5 | Tringle | Tringle de support du panneau haut | Ø3x450 | 2 |  |  | A plier en forme de U. Petites partie de 24mm de long
2.6.6 | DIN 315-M8-GT-C-C | Écrou à oreilles DIN 315 - M8 | M8 | 2 | 1,20 | 2,40 |  | Ayce Écrou à ailettes | M8 Acheter chez JUMBO (https://www.jumbo.ch/fr/gros-outillage-atelier/petite-quincaillerie/rondelles-plates-ecrous-gefundene-terminologie-eintraege4/ayce-ecrou-a-ailettes--m8/p/6930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)
2.6.7 | DIN EN 24015 - M8 x 60 | Vis tête hexagonale DIN EN 24015 - M8 x 60 | M8x60 | 2 | 1,00 | 2,00 |  | Ayce Vis à Tête Hexagonale | M8 Acheter chez JUMBO (https://www.jumbo.ch/fr/gros-outillage-atelier/petite-quincaillerie/vis/vis-a-metaux/ayce-vis-a-tete-hexagonale--m8/p/6930585)
2.6.8 | Miroir en Polystyrène | 100x200cm | Miroir en polystyrène pour déflecteurs | 2000x1000x2 | 1 | 72,00 | 72,00 | A découper selon plans | Miroir en Polystyrène | 100 × 200 cm Acheter chez JUMBO (https://www.jumbo.ch/fr/construction-renovation/verre-verre-synthetique/verre-synthetique/miroir-en-polystyrene--100--200-cm/p/3374634)
Total Four + Déflecteur (HT ni livraison) |  |  |  |  |  | 261,48
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

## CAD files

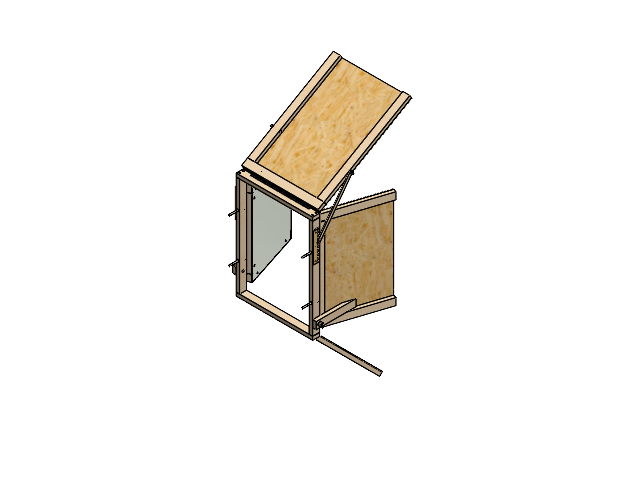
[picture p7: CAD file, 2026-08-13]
CAO/Solidworks/Assemblage_Déflecteurs_MOD.SLDASM
Tasseau_524_Cadre_Deflecteur x 3
Tasseau_680_Cadre_Deflecteur x 2
Planche_Déflecteur_Gauche
Tasseau_440_Deflecteur x 2
Tasseau_582_Deflecteur
cross fh tapping 7976_din x 60
Charnière_600 x 8
Adaptateur_Charnière
Planche_Déflecteur_Droite
Tasseau_415_Deflecteur x 3
Tasseau_482_Deflecteur
Planche_Déflecteur_Bas
Tasseau_627_Deflecteur x 2
Planche_Déflecteur_Haut
Tasseau_677_Deflecteur x 2
hex bolt gradeb_din x 2
plain washer grade a_din x 2
prevailing torque nut style 1 insert_din x 2
Tasseau_273_Deflecteur x 2
hex bolt gradeab_din x 6
hex nut gradec_iso x 4
plain washer large grade ac_iso x 2
wing nut 01_din x 2
cross ph tapping 968_din x 8
Réglage_Déflecteur x 2
Tringle_Bois x 2

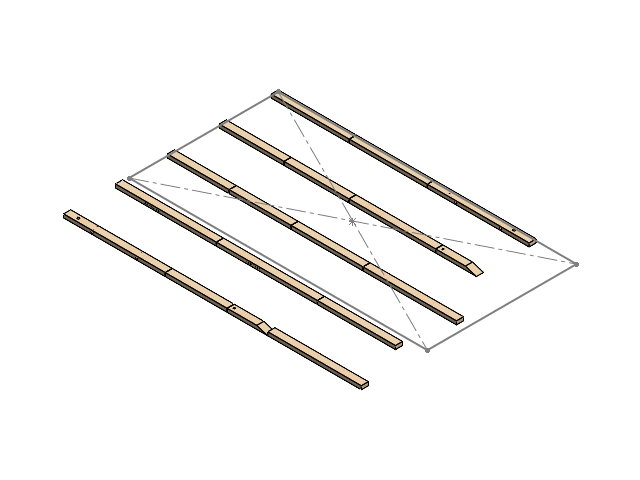
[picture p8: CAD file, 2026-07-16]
CAO/Solidworks/Découpe/Déflecteurs/Découpe_Tasseaux_Deflecteurs.SLDASM
Tasseau_524_Cadre_Deflecteur x 3
Tasseau_680_Cadre_Deflecteur x 2
Tasseau_582_Deflecteur
Tasseau_440_Deflecteur x 2
Tasseau_482_Deflecteur
Tasseau_415_Deflecteur x 3
Tasseau_627_Deflecteur x 2
Tasseau_677_Deflecteur x 2
Tasseau_273_Deflecteur x 2

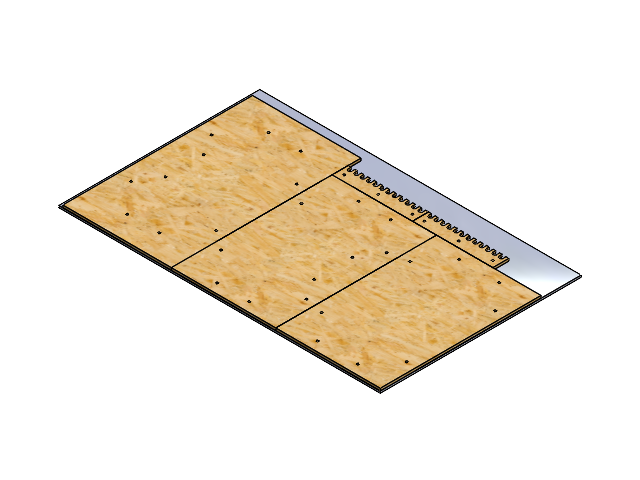
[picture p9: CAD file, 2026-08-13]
CAO/Solidworks/Découpe/Four/Découpe_6mm.SLDASM
Panneau_Base x 5
Base_Dessous x 2
Planche_Fermeture x 2
Planche_Derrière
Base_Coté x 4
Base_Fond x 2
Planche_Derrière_Grande
Base_Porte_Dessus x 2
Planche_Porte_Derrière_Grande
Réglage_Déflecteur x 2

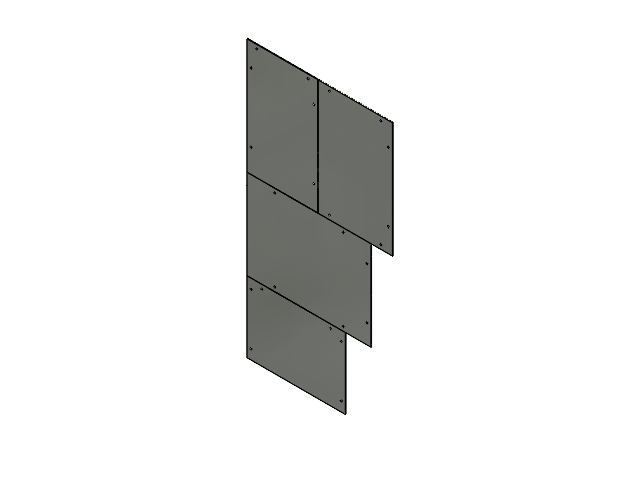
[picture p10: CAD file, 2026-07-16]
CAO/Solidworks/Découpe/Déflecteurs/Découpe_Panneaux.SLDASM
Planche_Déflecteur_Bas
Planche_Déflecteur_Droite
Planche_Déflecteur_Gauche
Planche_Déflecteur_Haut

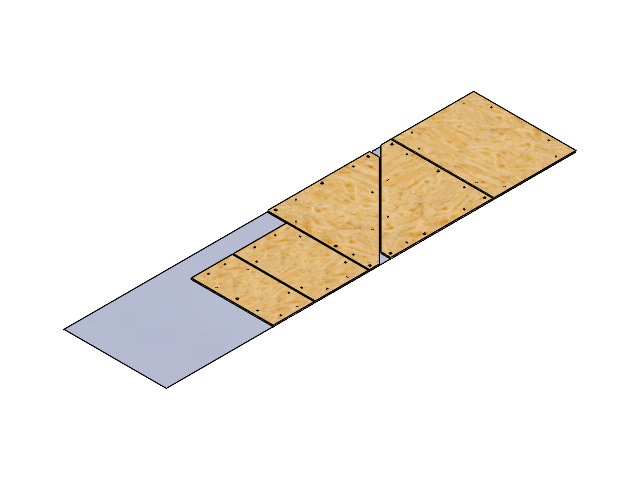
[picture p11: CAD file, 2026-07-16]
CAO/Solidworks/Découpe/Four/DécoupeMirroir.SLDASM
Mirroir_Base
Base_Dessous
Base_Fond
Base_Porte_Dessus
Base_Coté x 2

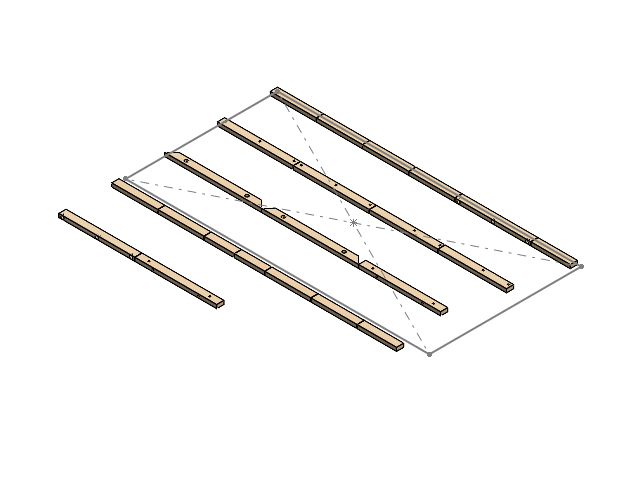
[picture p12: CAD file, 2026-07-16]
CAO/Solidworks/Découpe/Four/Découpe_Tasseaux_Four.SLDASM
Tasseau_304_Fond x 8
Tasseau_500_Dessous x 2
Tasseau_500_Parois x 2
Tasseau_452_Parois x 2
Tasseau_Parois_Biais x 4
Tasseau_200_Fond x 2
Tasseau_260_Porte x 2

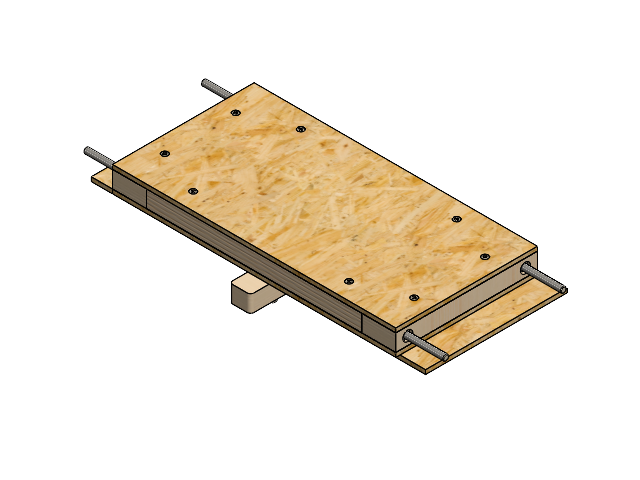
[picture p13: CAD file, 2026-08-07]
CAO/Solidworks/Assemblage_Fond.SLDASM
Base_Fond x 2
Tasseau_200_Fond x 2
Tasseau_304_Fond x 2
Isolation_Fond
Planche_Derrière_Grande
Fixation_Porte
Complément_isolation_fond
hex bolt gradeab_din x 5
hex nut gradec_din x 4
plain washer large grade ac_iso
cross fh tapping 7976_din x 16
prevailing torque nut style 1 insert_din

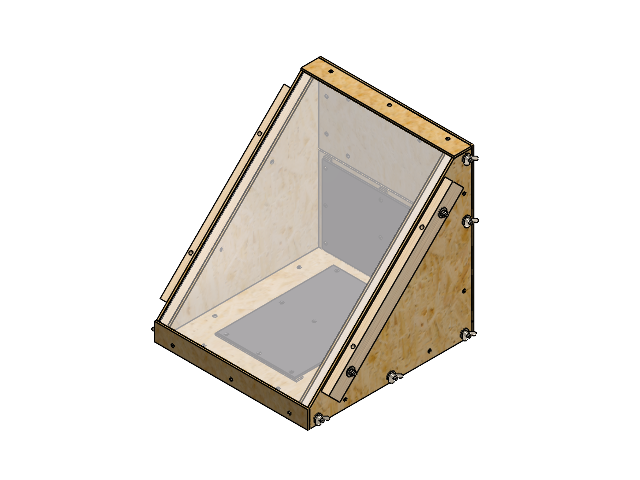
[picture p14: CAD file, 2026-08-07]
CAO/Solidworks/Assemblage_Four_Solaire.SLDASM
Base_Dessous x 2
Tasseau_304_dessous x 4
Tasseau_500_Dessous x 2
Isolation_Dessous x 3
Cale_Plaque_Acier x 6
Plaque_Acier x 2
Planche_Fermeture x 2
Planche_Derrière
Complément_isolation_dessous x 3
hex bolt gradeb_din x 6
hex nut gradec_din x 10
cross fh tapping 7976_din x 108
Base_Coté x 4
Tasseau_500_Parois x 2
Tasseau_Parois_Biais x 4
Tasseau_452_Parois x 2
Isolation_Parois_Verticale x 2
Complément_isolation_parois x 2
hex bolt gradeab_din x 9
plain washer large grade ac_iso x 15
prevailing torque nut style 1 insert_din x 5
Base_Fond x 2
Tasseau_200_Fond x 2
Tasseau_304_Fond x 2
Isolation_Fond
Planche_Derrière_Grande
Fixation_Porte
Complément_isolation_fond
Planche_Porte_Derrière_Grande
Base_Porte_Dessus x 2
Tasseau_260_Porte x 2
Tasseau_304_porte x 2
Isolation_Porte
complément_isolation_porte
Poignée_Porte
Charnière_Part1 x 4
Vitre
wing nut 01_din x 10

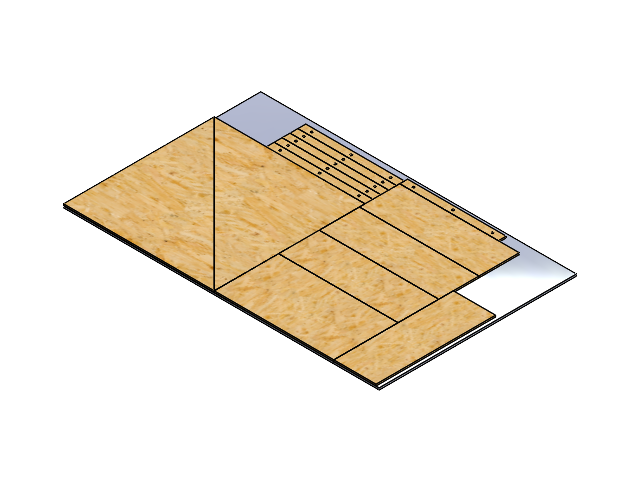
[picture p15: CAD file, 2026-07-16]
CAO/Solidworks/Découpe/Four/Découpe_4mm.SLDASM
Panneau_Base
Complément_isolation_dessous x 3
Complément_isolation_fond
Complément_isolation_parois x 2
complément_isolation_porte
Cale_Plaque_Acier x 6

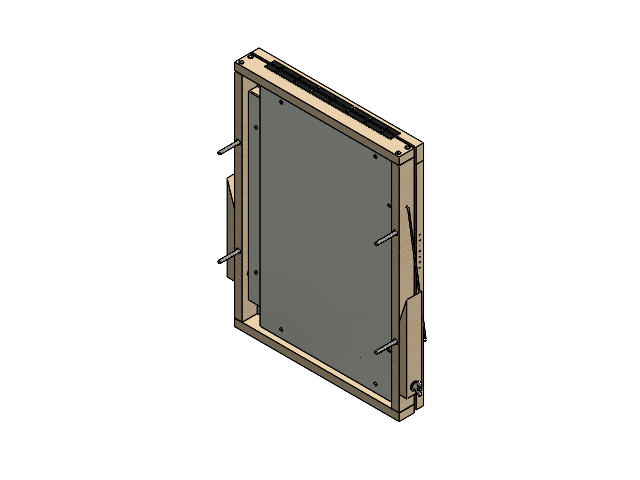
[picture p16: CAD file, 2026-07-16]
CAO/Solidworks/Assemblage_Déflecteurs.SLDASM
Tasseau_524_Cadre_Deflecteur x 3
Tasseau_680_Cadre_Deflecteur x 2
Planche_Déflecteur_Gauche
Tasseau_440_Deflecteur x 2
Tasseau_582_Deflecteur
cross fh tapping 7976_din x 60
Charnière_600 x 8
Adaptateur_Charnière
Planche_Déflecteur_Droite
Tasseau_415_Deflecteur x 3
Tasseau_482_Deflecteur
Planche_Déflecteur_Bas
Tasseau_627_Deflecteur x 2
Planche_Déflecteur_Haut
Tasseau_677_Deflecteur x 2
Tasseau_273_Deflecteur x 2
Tringle x 2
hex bolt gradeab_din x 6
hex nut gradec_iso x 4
plain washer large grade ac_iso x 2
wing nut 01_din x 2
cross ph tapping 968_din x 8

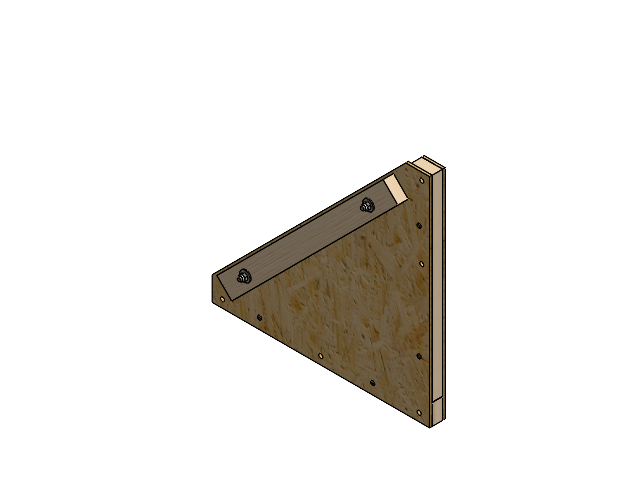
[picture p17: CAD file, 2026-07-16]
CAO/Solidworks/Assemblage_Parois.SLDASM
Base_Coté x 2
Tasseau_500_Parois
Tasseau_Parois_Biais x 2
Tasseau_452_Parois
Isolation_Parois_Verticale
Complément_isolation_parois
hex bolt gradeab_din x 2
plain washer large grade ac_iso x 2
prevailing torque nut style 1 insert_din x 2
cross fh tapping 7976_din x 12

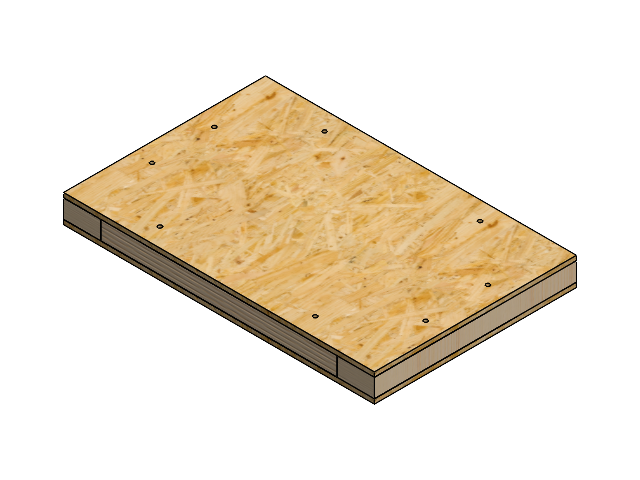
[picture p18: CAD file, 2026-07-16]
CAO/Solidworks/Assemblage_Parois_Porte.SLDASM
Base_Porte_Dessus x 2
Tasseau_260_Porte x 2
Tasseau_304_porte x 2
Isolation_Porte
complément_isolation_porte

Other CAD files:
CAO/STEP/Assemblage_Parois_G_Emport_Suppl.STEP
CAO/STEP/Assemblage_Déflecteur_Bas.STEP
CAO/STEP/Assemblage_Dessous.STEP
CAO/STEP/Assemblage_Déflecteurs_Ouvert.STEP
CAO/STEP/Assemblage_Déflecteur_Droite.STEP
CAO/STEP/Assemblage_Porte.STEP
CAO/STEP/Adaptateur_Charnière.STEP
CAO/STEP/Assemblage_Déflecteur_Gauche.STEP
CAO/STEP/Assemblage_Déflecteur_Haut.STEP
CAO/STEP/Assemblage_Fond_Avec_vis.STEP
CAO/STEP/Assemblage_Four_Deflecteur.STEP
CAO/STEP/Assemblage_Four_Solaire_Simple.STEP
CAO/STEP/Assemblage_Parois_D_Emport_Suppl.STEP
CAO/STEP/Base_Coté_Droite.STEP
CAO/STEP/Base_Coté_DroiteTrouSuppl.STEP
CAO/STEP/Base_Coté_Gauche.STEP
CAO/STEP/Base_Coté_GaucheTrouSuppl.STEP
CAO/STEP/Base_Dessous_Bas.STEP
CAO/STEP/Base_Dessous_Haut.STEP
CAO/STEP/Base_Fond_Externe.STEP
CAO/STEP/Base_Fond_Interne.STEP
CAO/STEP/Base_Porte_Dessus_Bas.STEP
CAO/STEP/Base_Porte_Dessus_Haut.STEP
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

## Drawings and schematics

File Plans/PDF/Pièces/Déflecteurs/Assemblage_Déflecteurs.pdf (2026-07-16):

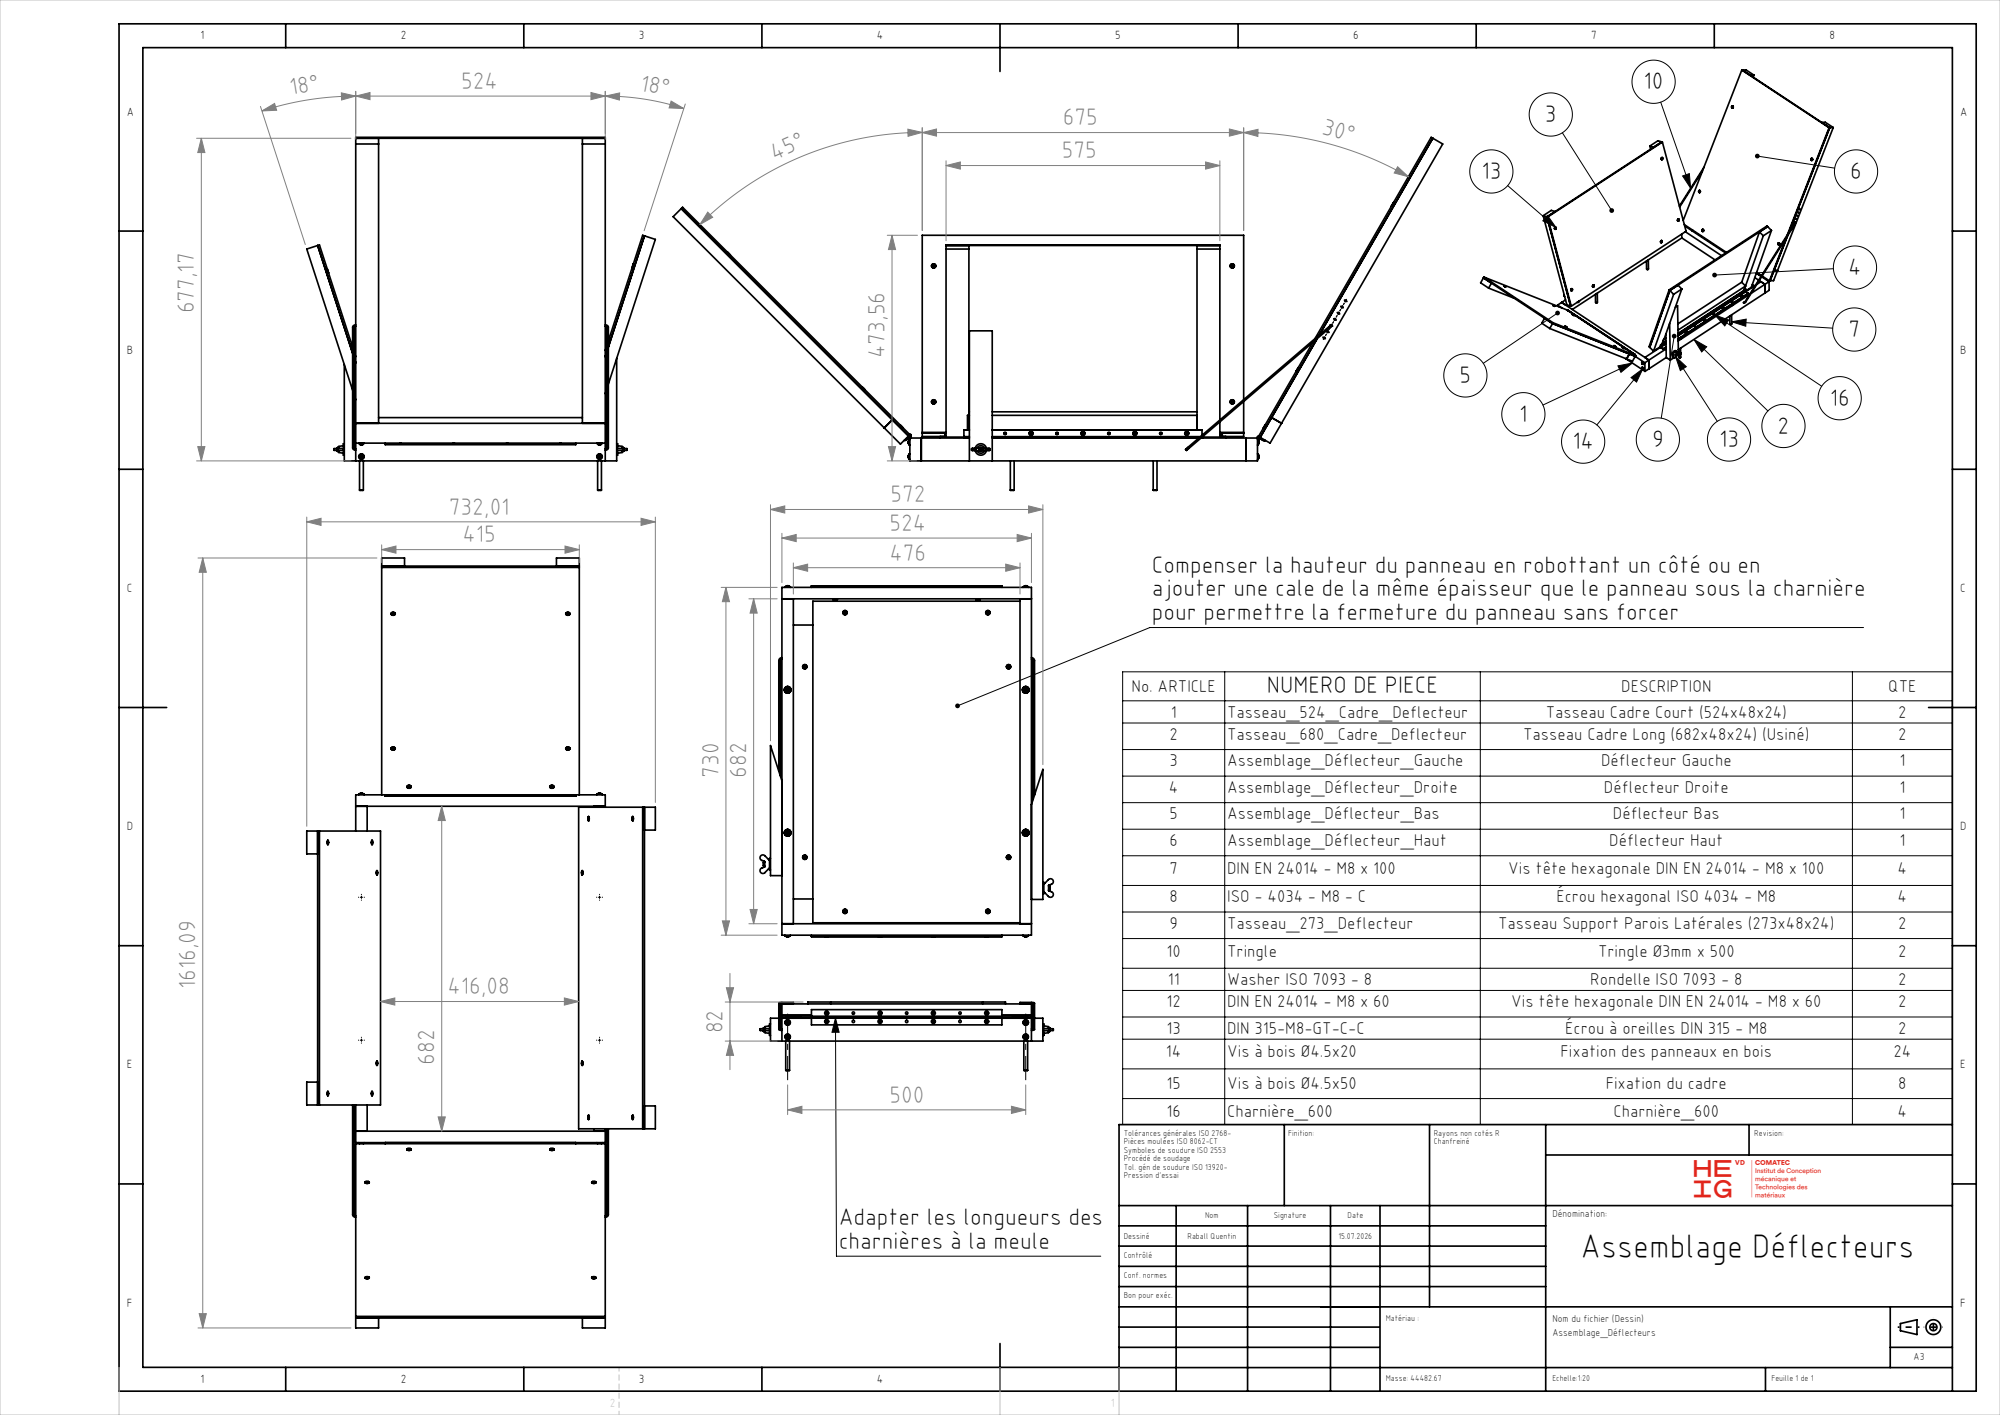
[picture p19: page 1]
Matériau :; Masse: 44482.67; Feuille 1 de 1; Raball Quentin; Assemblage Déflecteurs

Compenser la hauteur du panneau en robottant un côté ou en
ajouter une cale de la même épaisseur que le panneau sous la charnière
pour permettre la fermeture du panneau sans forcer

No. ARTICLE | NUMERO DE PIECE | DESCRIPTION | QTE
1 | Tasseau_524_Cadre_Deflecteur | Tasseau Cadre Court (524x48x24) | 2
2 | Tasseau_680_Cadre_Deflecteur | Tasseau Cadre Long (682x48x24) (Usiné) | 2
3 | Assemblage_Déflecteur_Gauche | Déflecteur Gauche | 1
4 | Assemblage_Déflecteur_Droite | Déflecteur Droite | 1
5 | Assemblage_Déflecteur_Bas | Déflecteur Bas | 1
6 | Assemblage_Déflecteur_Haut | Déflecteur Haut | 1
7 | DIN EN 24014 - M8 x 100 | Vis tête hexagonale DIN EN 24014 - M8 x 100 | 4
8 | ISO - 4034 - M8 - C | Écrou hexagonal ISO 4034 - M8 | 4
9 | Tasseau_273_Deflecteur | Tasseau Support Parois Latérales (273x48x24) | 2
10 | Tringle | Tringle Ø3mm x 500 | 2
11 | Washer ISO 7093 - 8 | Rondelle ISO 7093 - 8 | 2
12 | DIN EN 24014 - M8 x 60 | Vis tête hexagonale DIN EN 24014 - M8 x 60 | 2
13 | DIN 315-M8-GT-C-C | Écrou à oreilles DIN 315 - M8 | 2
14 | Vis à bois Ø4.5x20 | Fixation des panneaux en bois | 24
15 | Vis à bois Ø4.5x50 | Fixation du cadre | 8
16 | Charnière_600 | Charnière_600 | 4

Tolérances générales ISO 2768-
Pièces moulées ISO 8062-CT
Symboles de soudure ISO 2553
Procédé de soudage
Tol. gén de soudure ISO 13920-
Pression d'essai

Rayons non cotés R
Chanfreiné

Adapter les longueurs des
charnières à la meule

Dessiné
Contrôlé
Conf. normes
Bon pour exéc.

Nom du fichier (Dessin)
Assemblage_Déflecteurs

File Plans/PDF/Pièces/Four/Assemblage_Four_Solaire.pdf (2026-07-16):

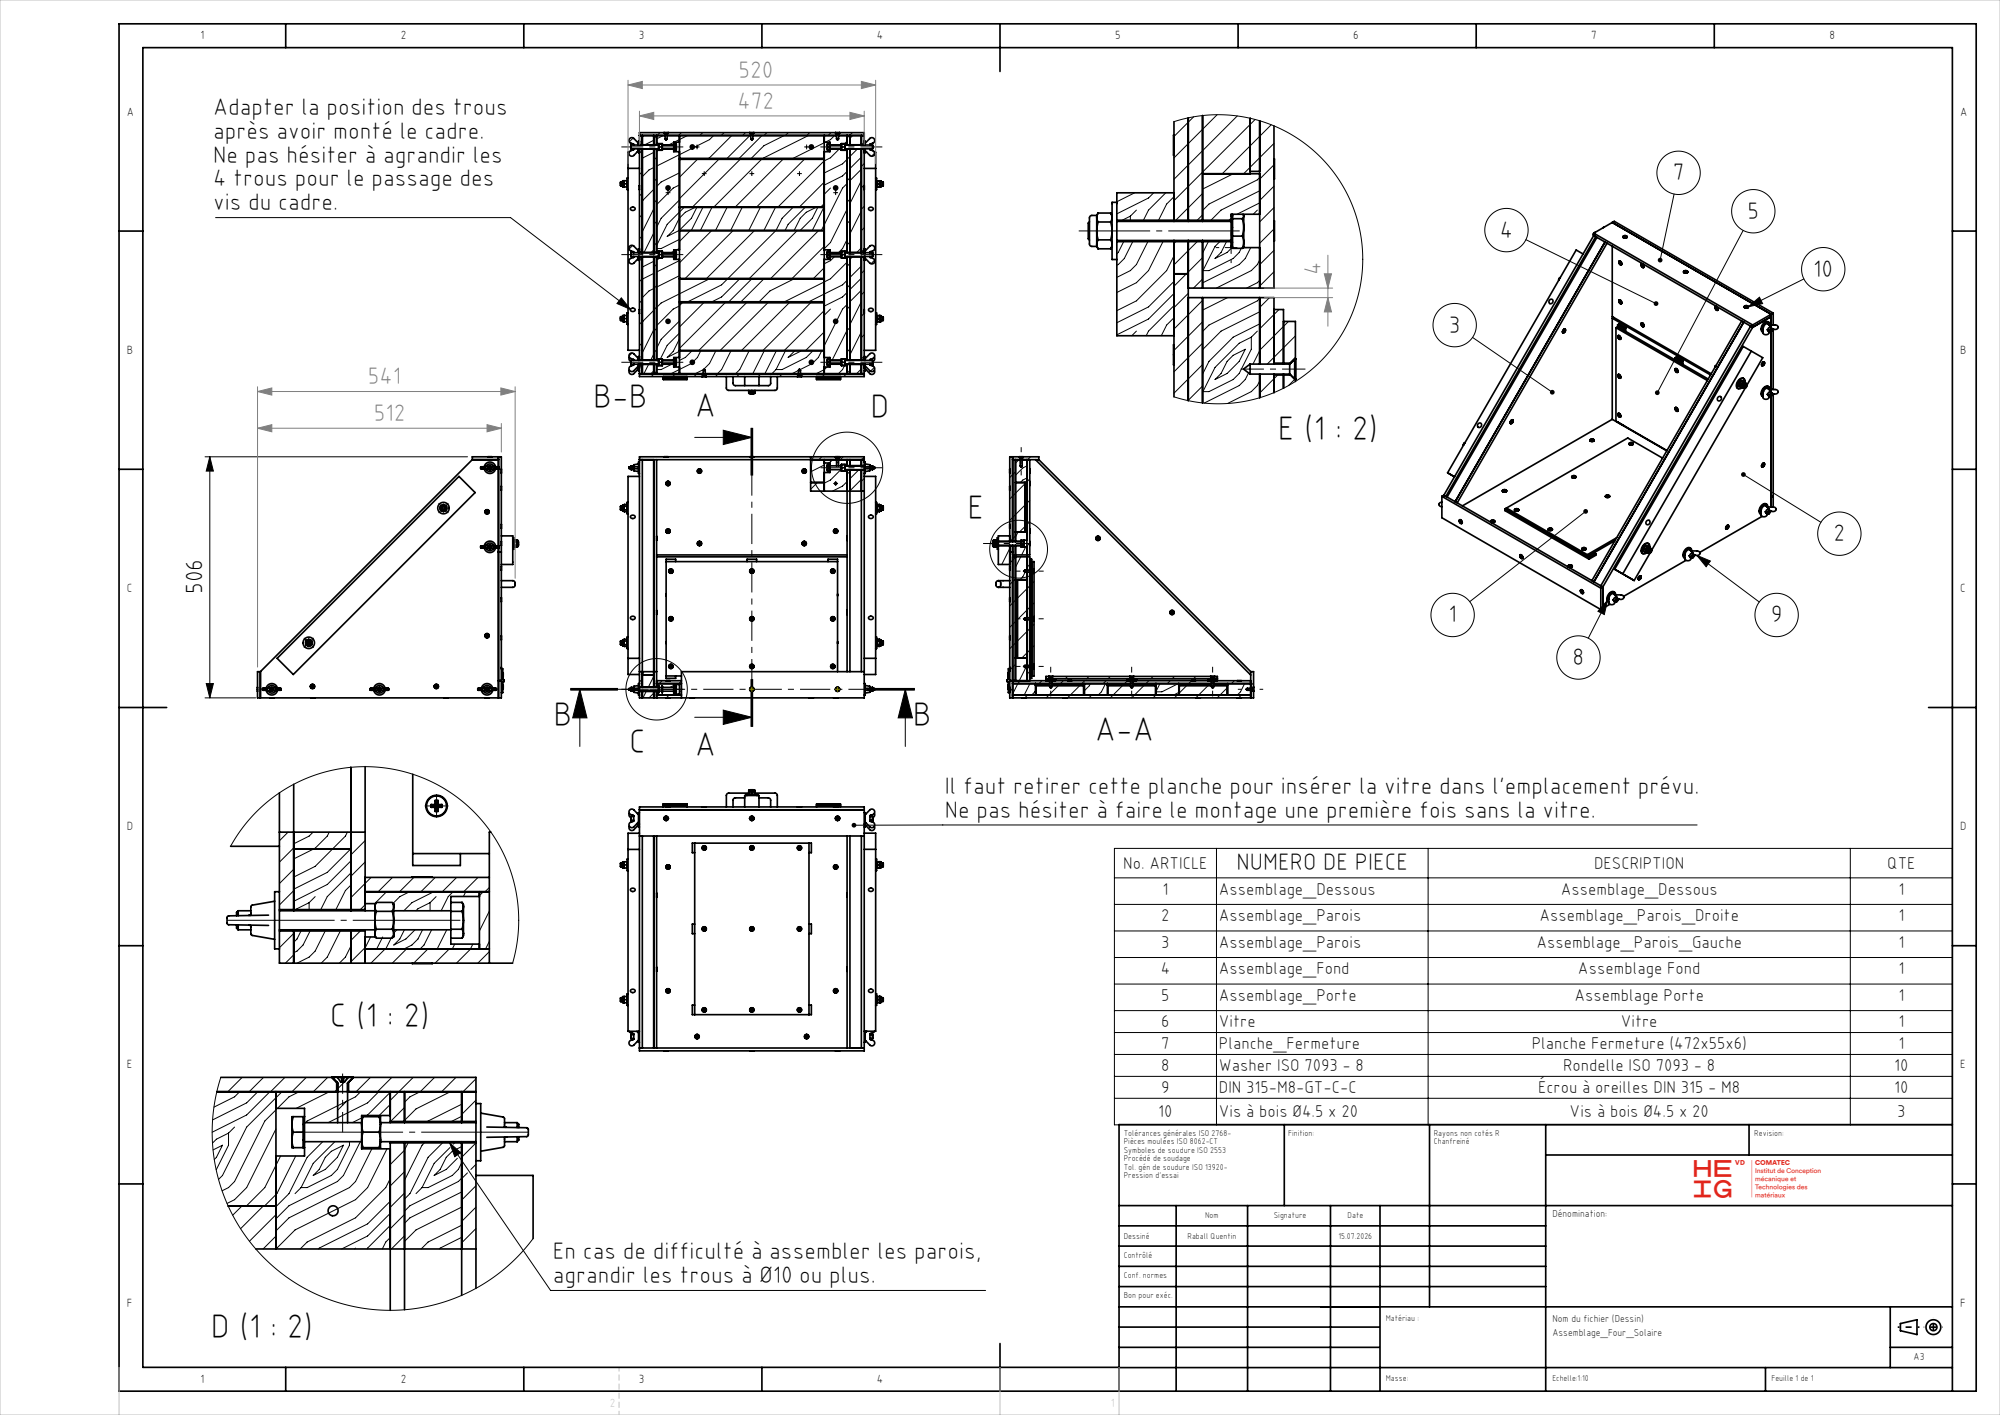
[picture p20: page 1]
Matériau :; Feuille 1 de 1; Raball Quentin

Adapter la position des trous
après avoir monté le cadre.
Ne pas hésiter à agrandir les
4 trous pour le passage des
vis du cadre.

Il faut retirer cette planche pour insérer la vitre dans l'emplacement prévu.
Ne pas hésiter à faire le montage une première fois sans la vitre.

No. ARTICLE | NUMERO DE PIECE | DESCRIPTION | QTE
1 | Assemblage_Dessous | Assemblage_Dessous | 1
2 | Assemblage_Parois | Assemblage_Parois_Droite | 1
3 | Assemblage_Parois | Assemblage_Parois_Gauche | 1
4 | Assemblage_Fond | Assemblage Fond | 1
5 | Assemblage_Porte | Assemblage Porte | 1
6 | Vitre | Vitre | 1
7 | Planche_Fermeture | Planche Fermeture (472x55x6) | 1
8 | Washer ISO 7093 - 8 | Rondelle ISO 7093 - 8 | 10
9 | DIN 315-M8-GT-C-C | Écrou à oreilles DIN 315 - M8 | 10
10 | Vis à bois Ø4.5 x 20 | Vis à bois Ø4.5 x 20 | 3

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

Rayons non cotés R
Chanfreiné

En cas de difficulté à assembler les parois,
agrandir les trous à Ø10 ou plus.

Dessiné
Contrôlé
Conf. normes
Bon pour exéc.

Nom du fichier (Dessin)
Assemblage_Four_Solaire

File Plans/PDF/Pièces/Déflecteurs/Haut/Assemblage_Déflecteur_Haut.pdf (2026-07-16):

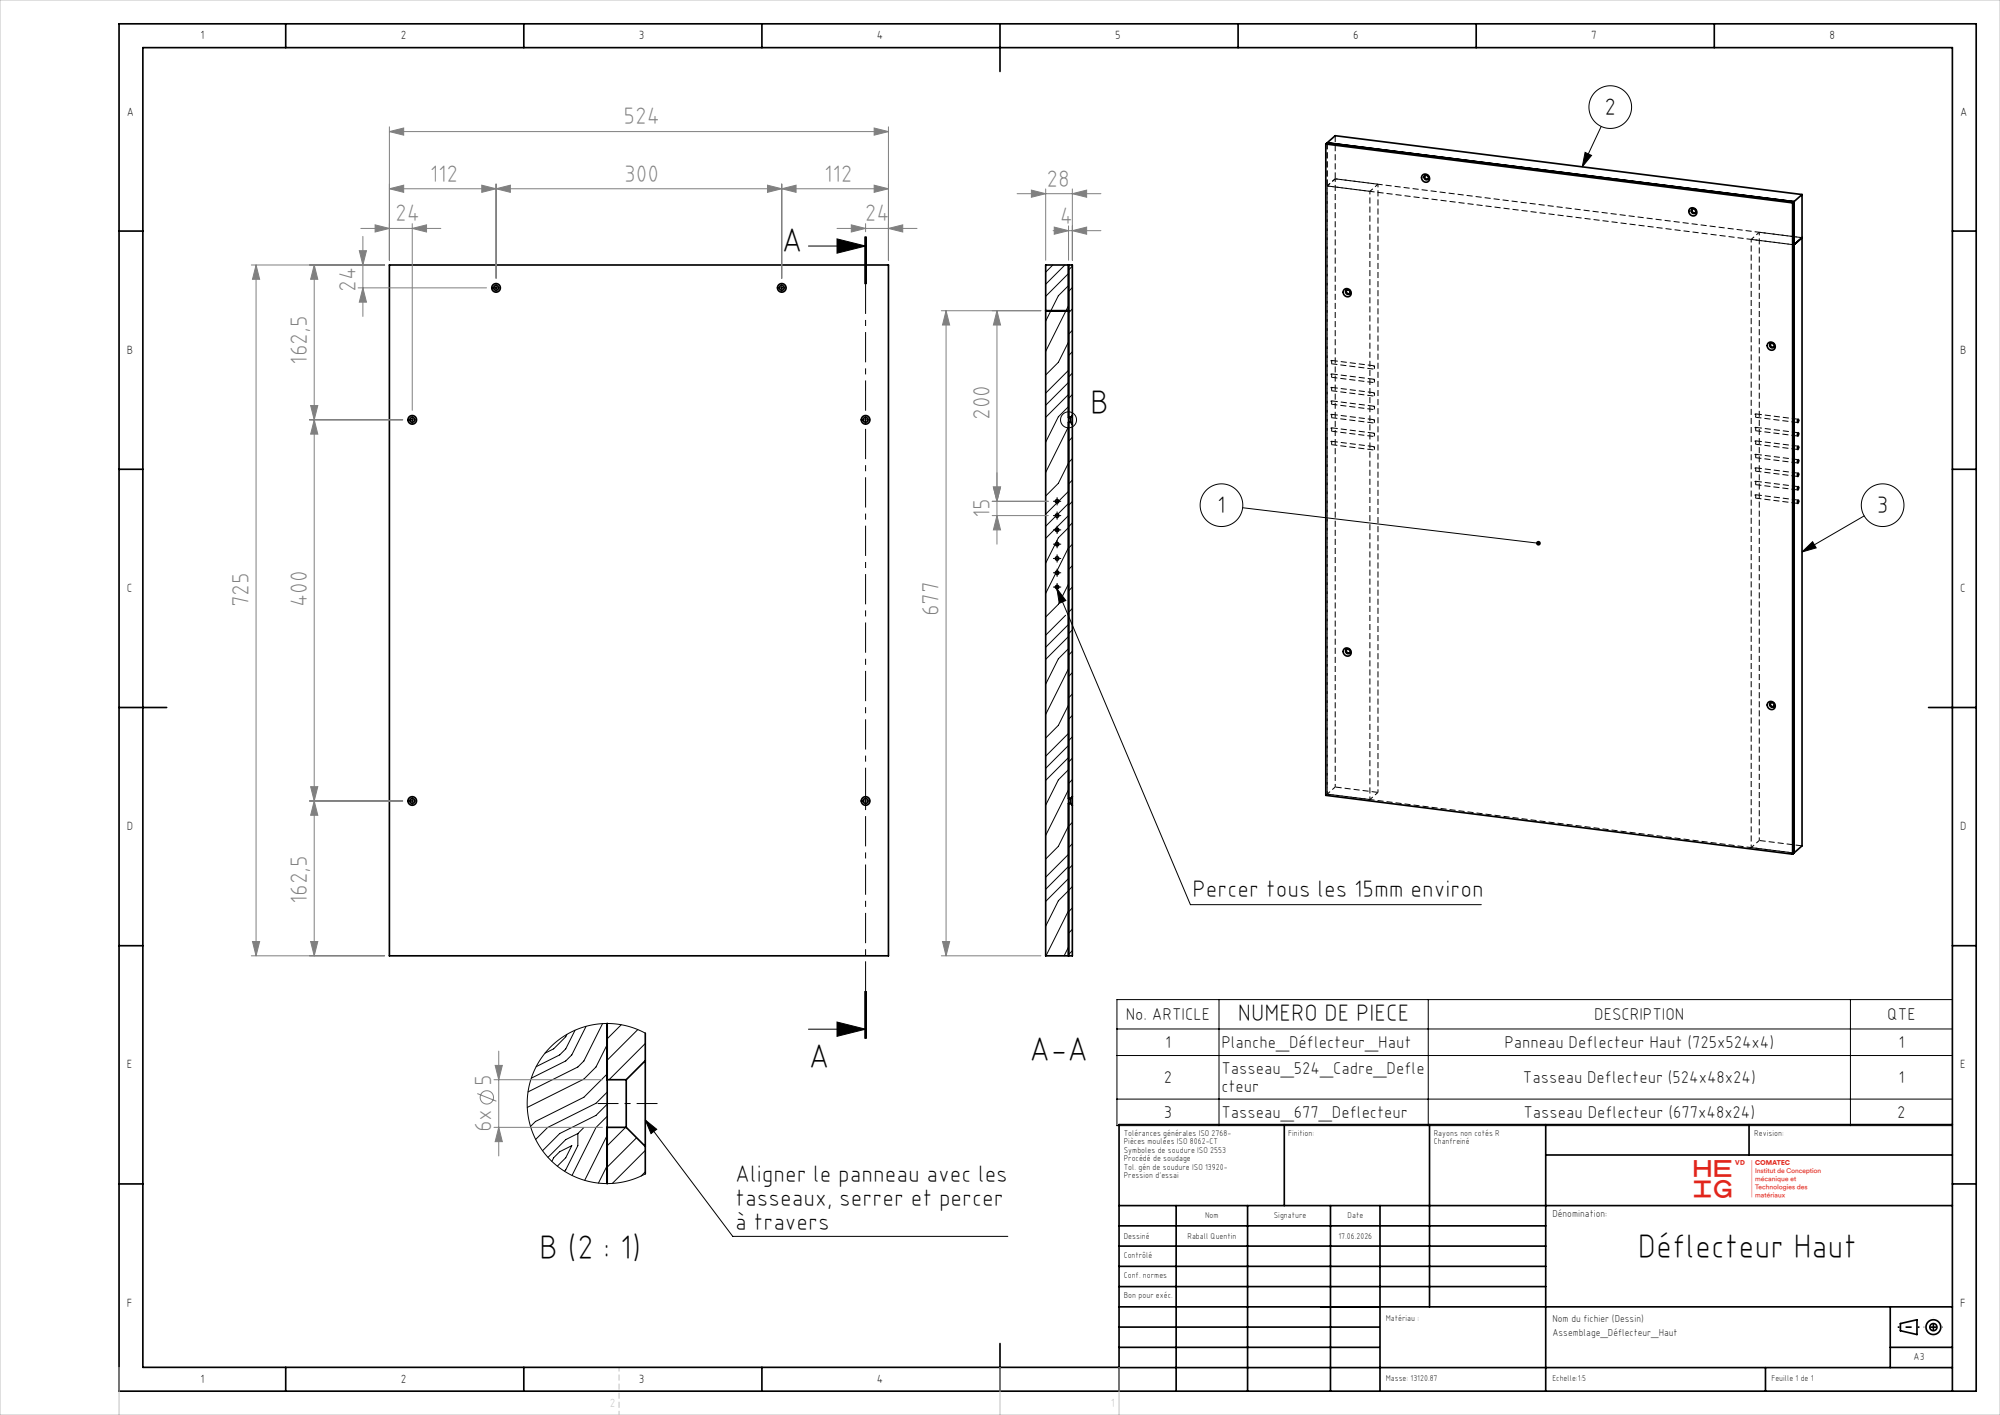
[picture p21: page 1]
Matériau :; Masse: 13120.87; Feuille 1 de 1; Raball Quentin; Déflecteur Haut

Percer tous les 15mm environ

No. ARTICLE | NUMERO DE PIECE | DESCRIPTION | QTE
1 | Planche_Déflecteur_Haut | Panneau Deflecteur Haut (725x524x4) | 1
2 | Tasseau_524_Cadre_Defle cteur | Tasseau Deflecteur (524x48x24) | 1

3 | Tasseau_677_Deflecteur | Tasseau Deflecteur (677x48x24) | 2

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

Rayons non cotés R
Chanfreiné

Aligner le panneau avec les
tasseaux, serrer et percer
à travers

Dessiné
Contrôlé
Conf. normes
Bon pour exéc.

Nom du fichier (Dessin)
Assemblage_Déflecteur_Haut

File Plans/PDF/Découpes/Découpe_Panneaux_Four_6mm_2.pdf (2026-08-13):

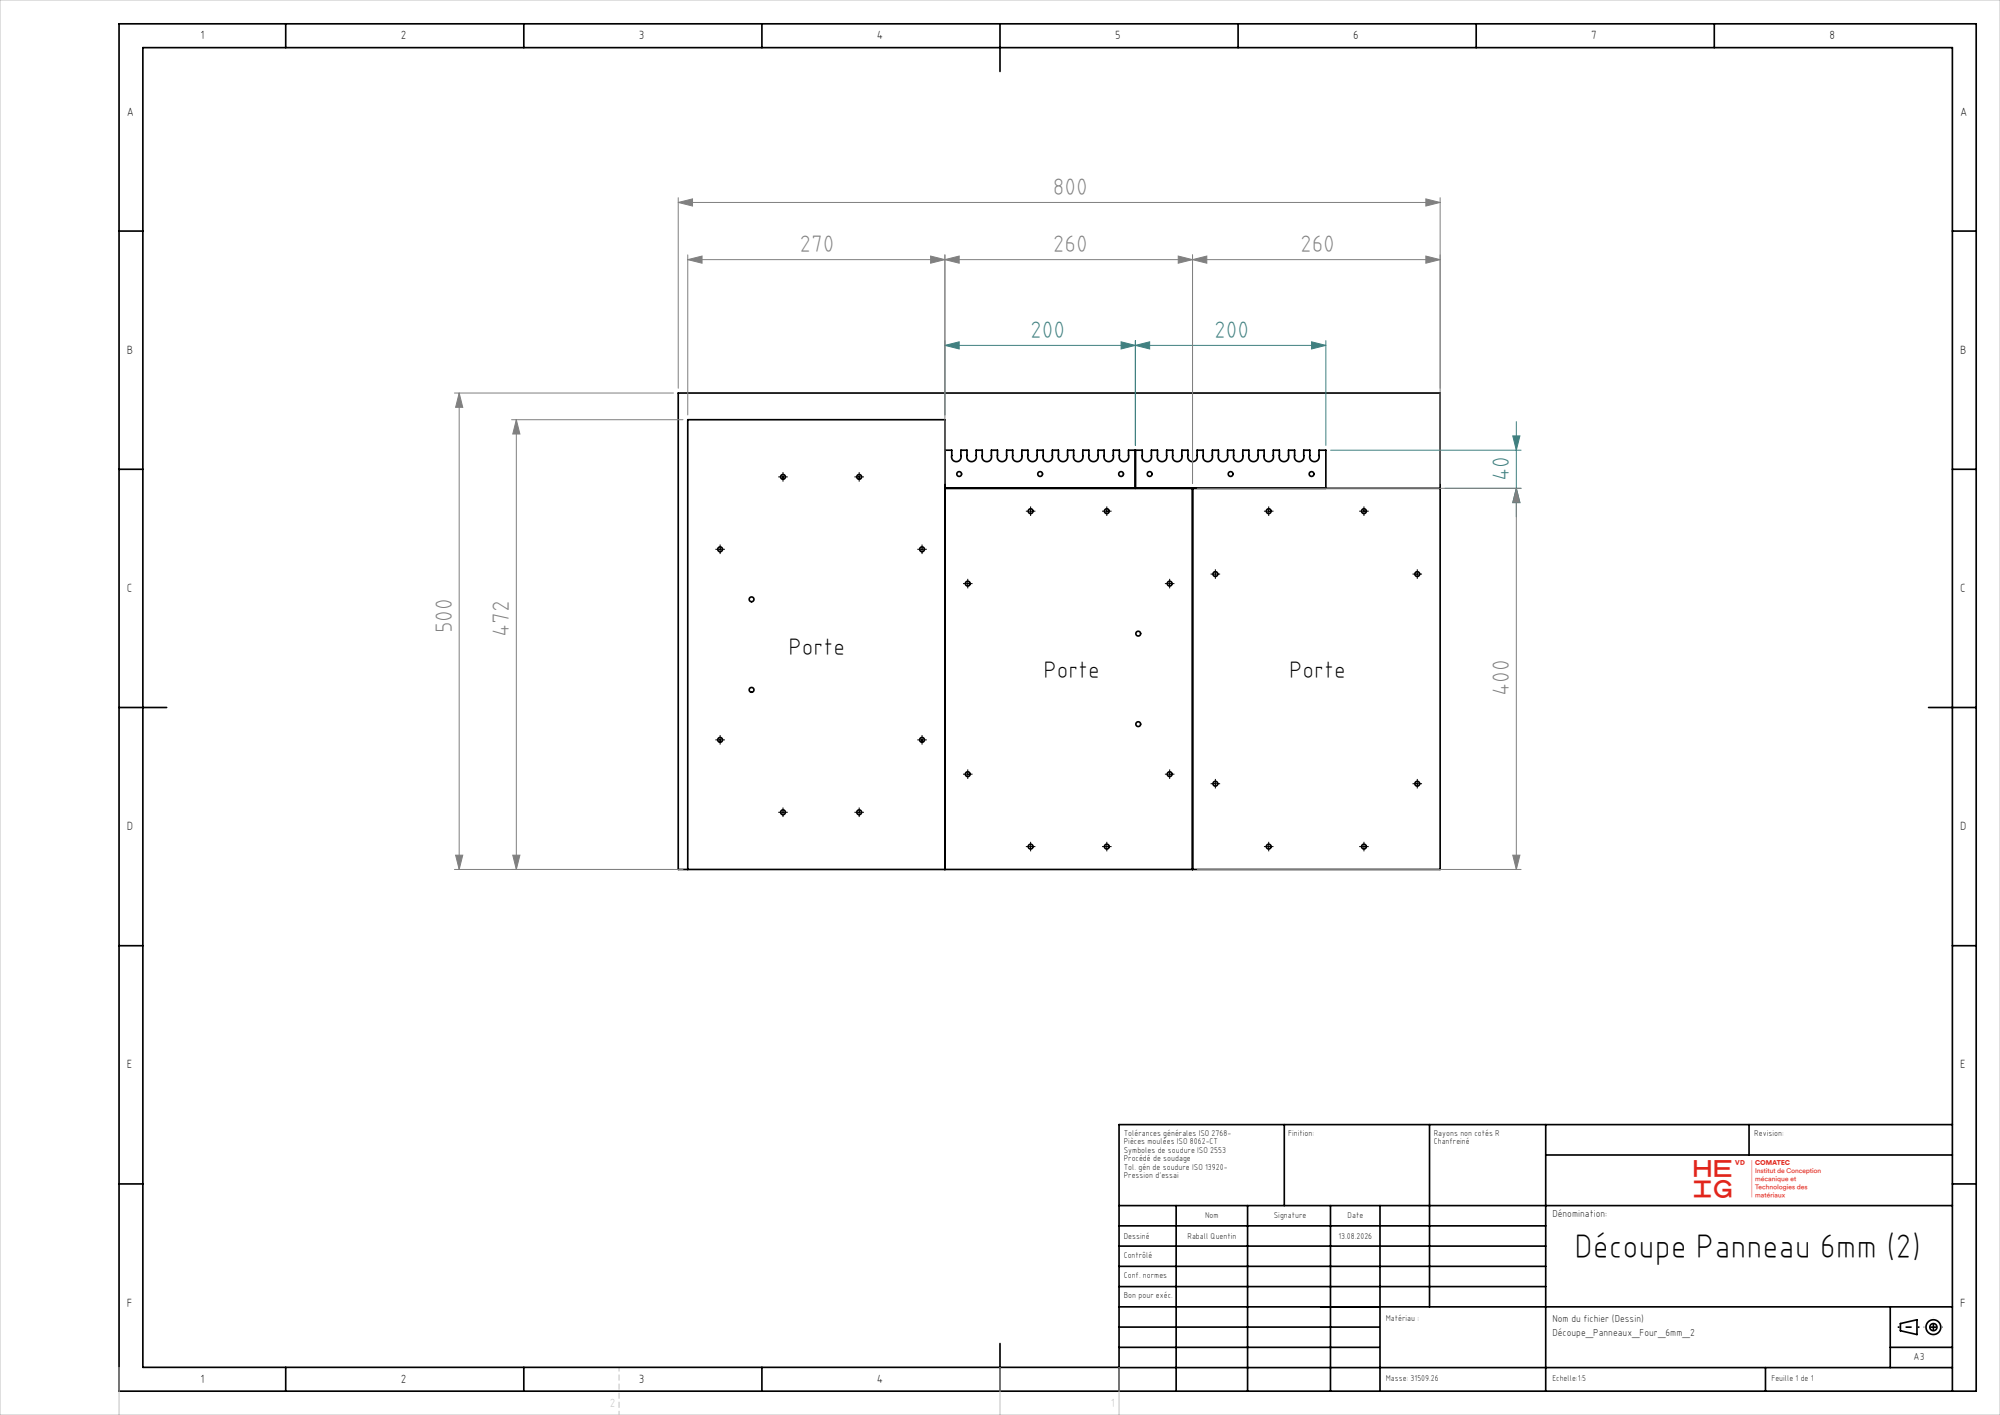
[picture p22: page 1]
Matériau :; Masse: 31509.26; Feuille 1 de 1; Raball Quentin; Découpe Panneau 6mm (2)

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

Rayons non cotés R
Chanfreiné

Dessiné
Contrôlé
Conf. normes
Bon pour exéc.

Nom du fichier (Dessin)
Découpe_Panneaux_Four_6mm_2

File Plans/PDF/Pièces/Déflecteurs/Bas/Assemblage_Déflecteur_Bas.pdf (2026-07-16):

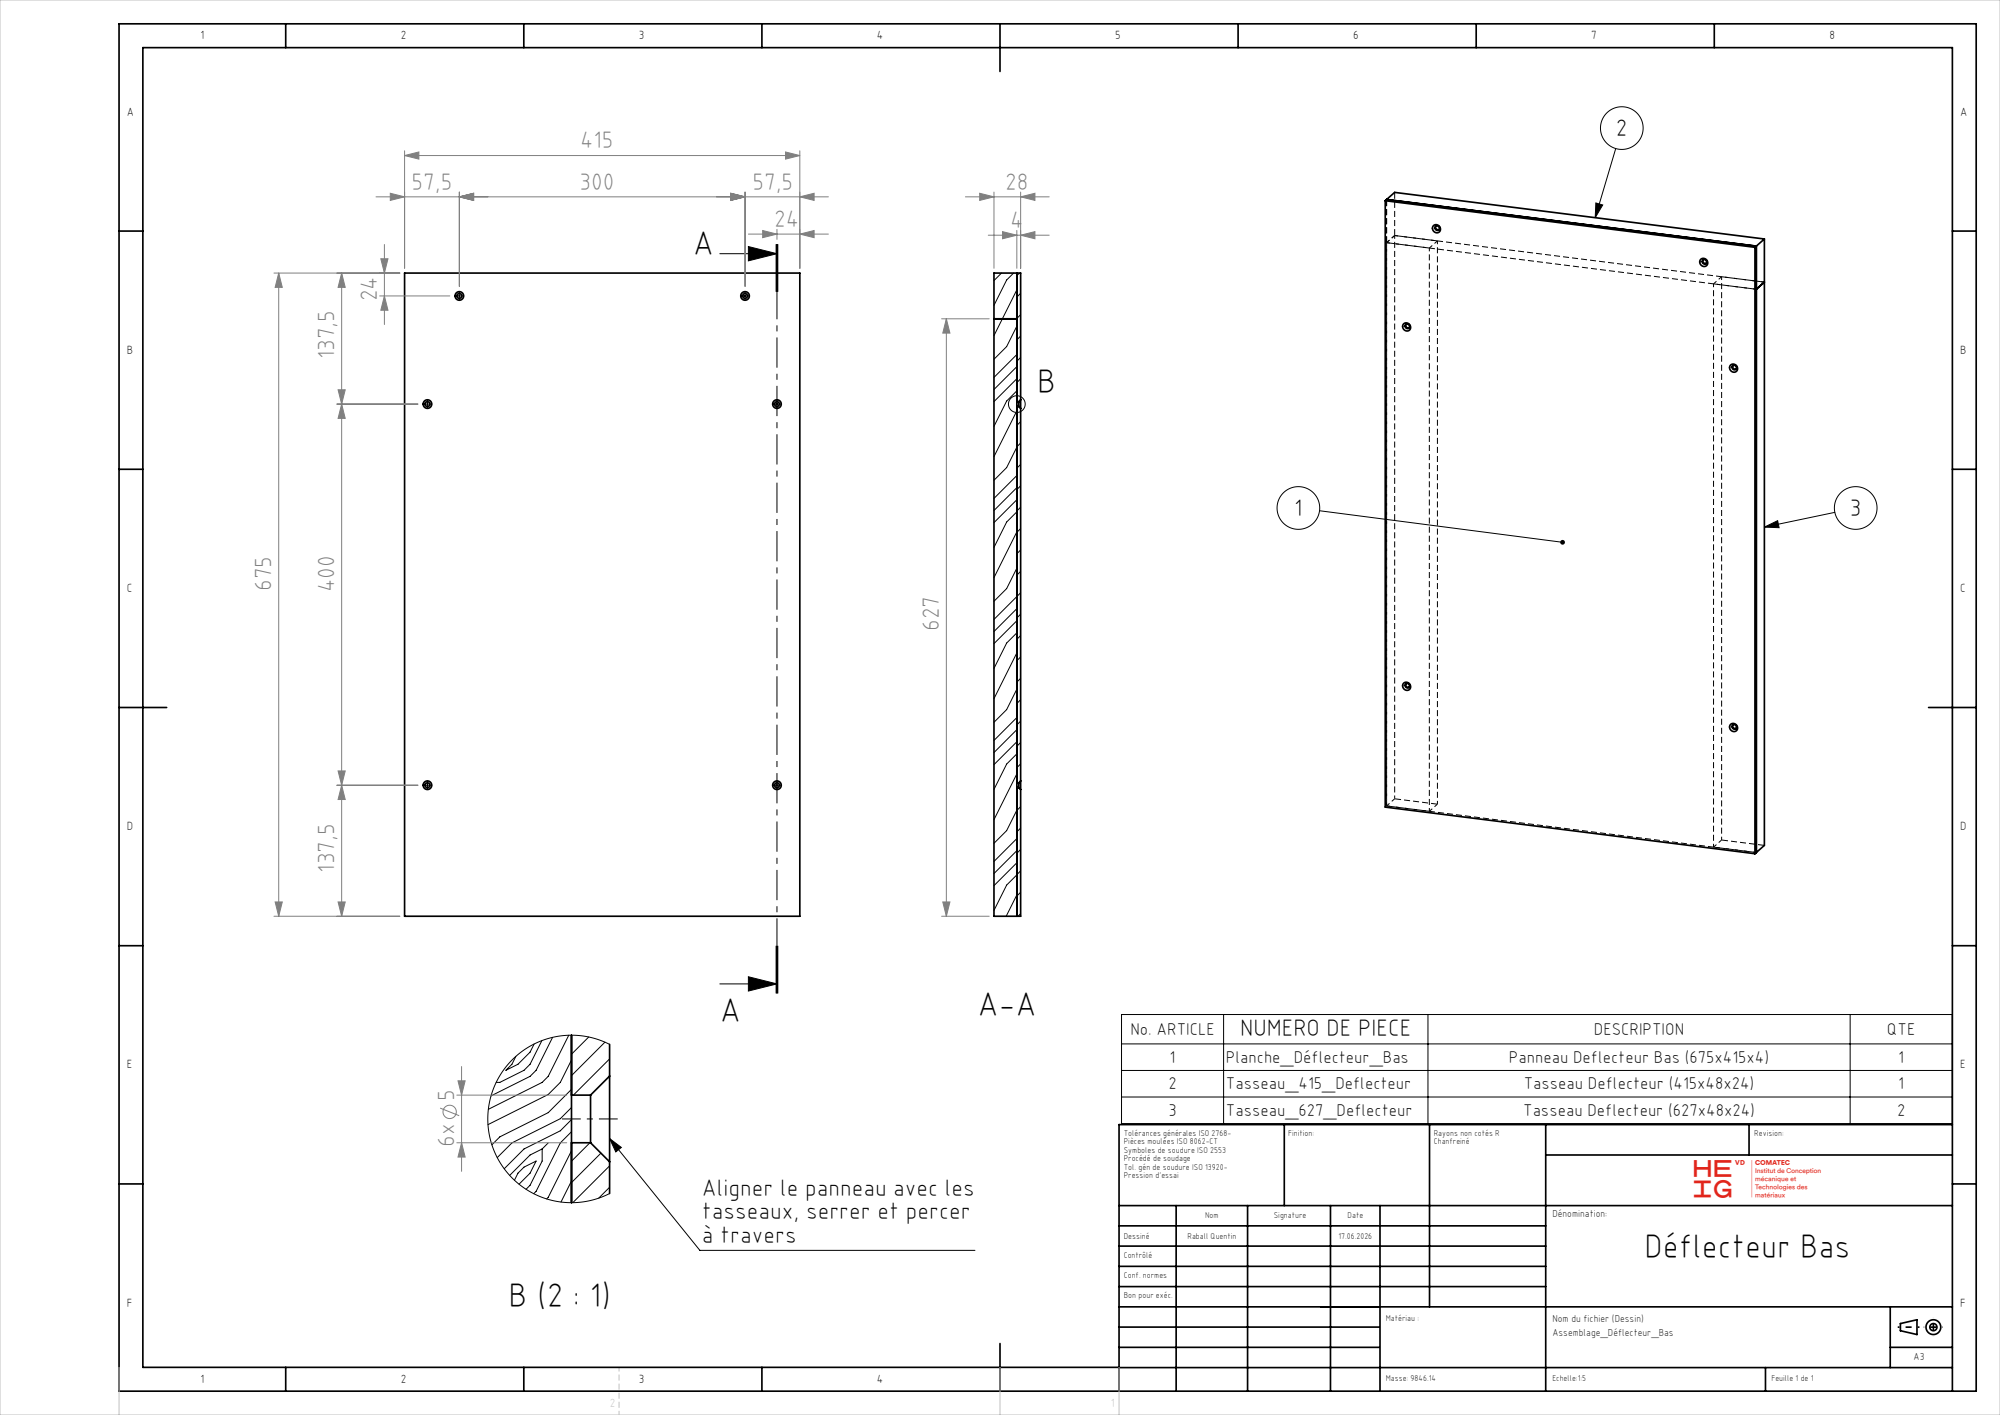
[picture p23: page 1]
Matériau :; Masse: 9846.14; Feuille 1 de 1; Raball Quentin; Déflecteur Bas

No. ARTICLE | NUMERO DE PIECE | DESCRIPTION | QTE
1 | Planche_Déflecteur_Bas | Panneau Deflecteur Bas (675x415x4) | 1
2 | Tasseau_415_Deflecteur | Tasseau Deflecteur (415x48x24) | 1
3 | Tasseau_627_Deflecteur | Tasseau Deflecteur (627x48x24) | 2

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

Rayons non cotés R
Chanfreiné

Aligner le panneau avec les
tasseaux, serrer et percer
à travers

Dessiné
Contrôlé
Conf. normes
Bon pour exéc.

Nom du fichier (Dessin)
Assemblage_Déflecteur_Bas

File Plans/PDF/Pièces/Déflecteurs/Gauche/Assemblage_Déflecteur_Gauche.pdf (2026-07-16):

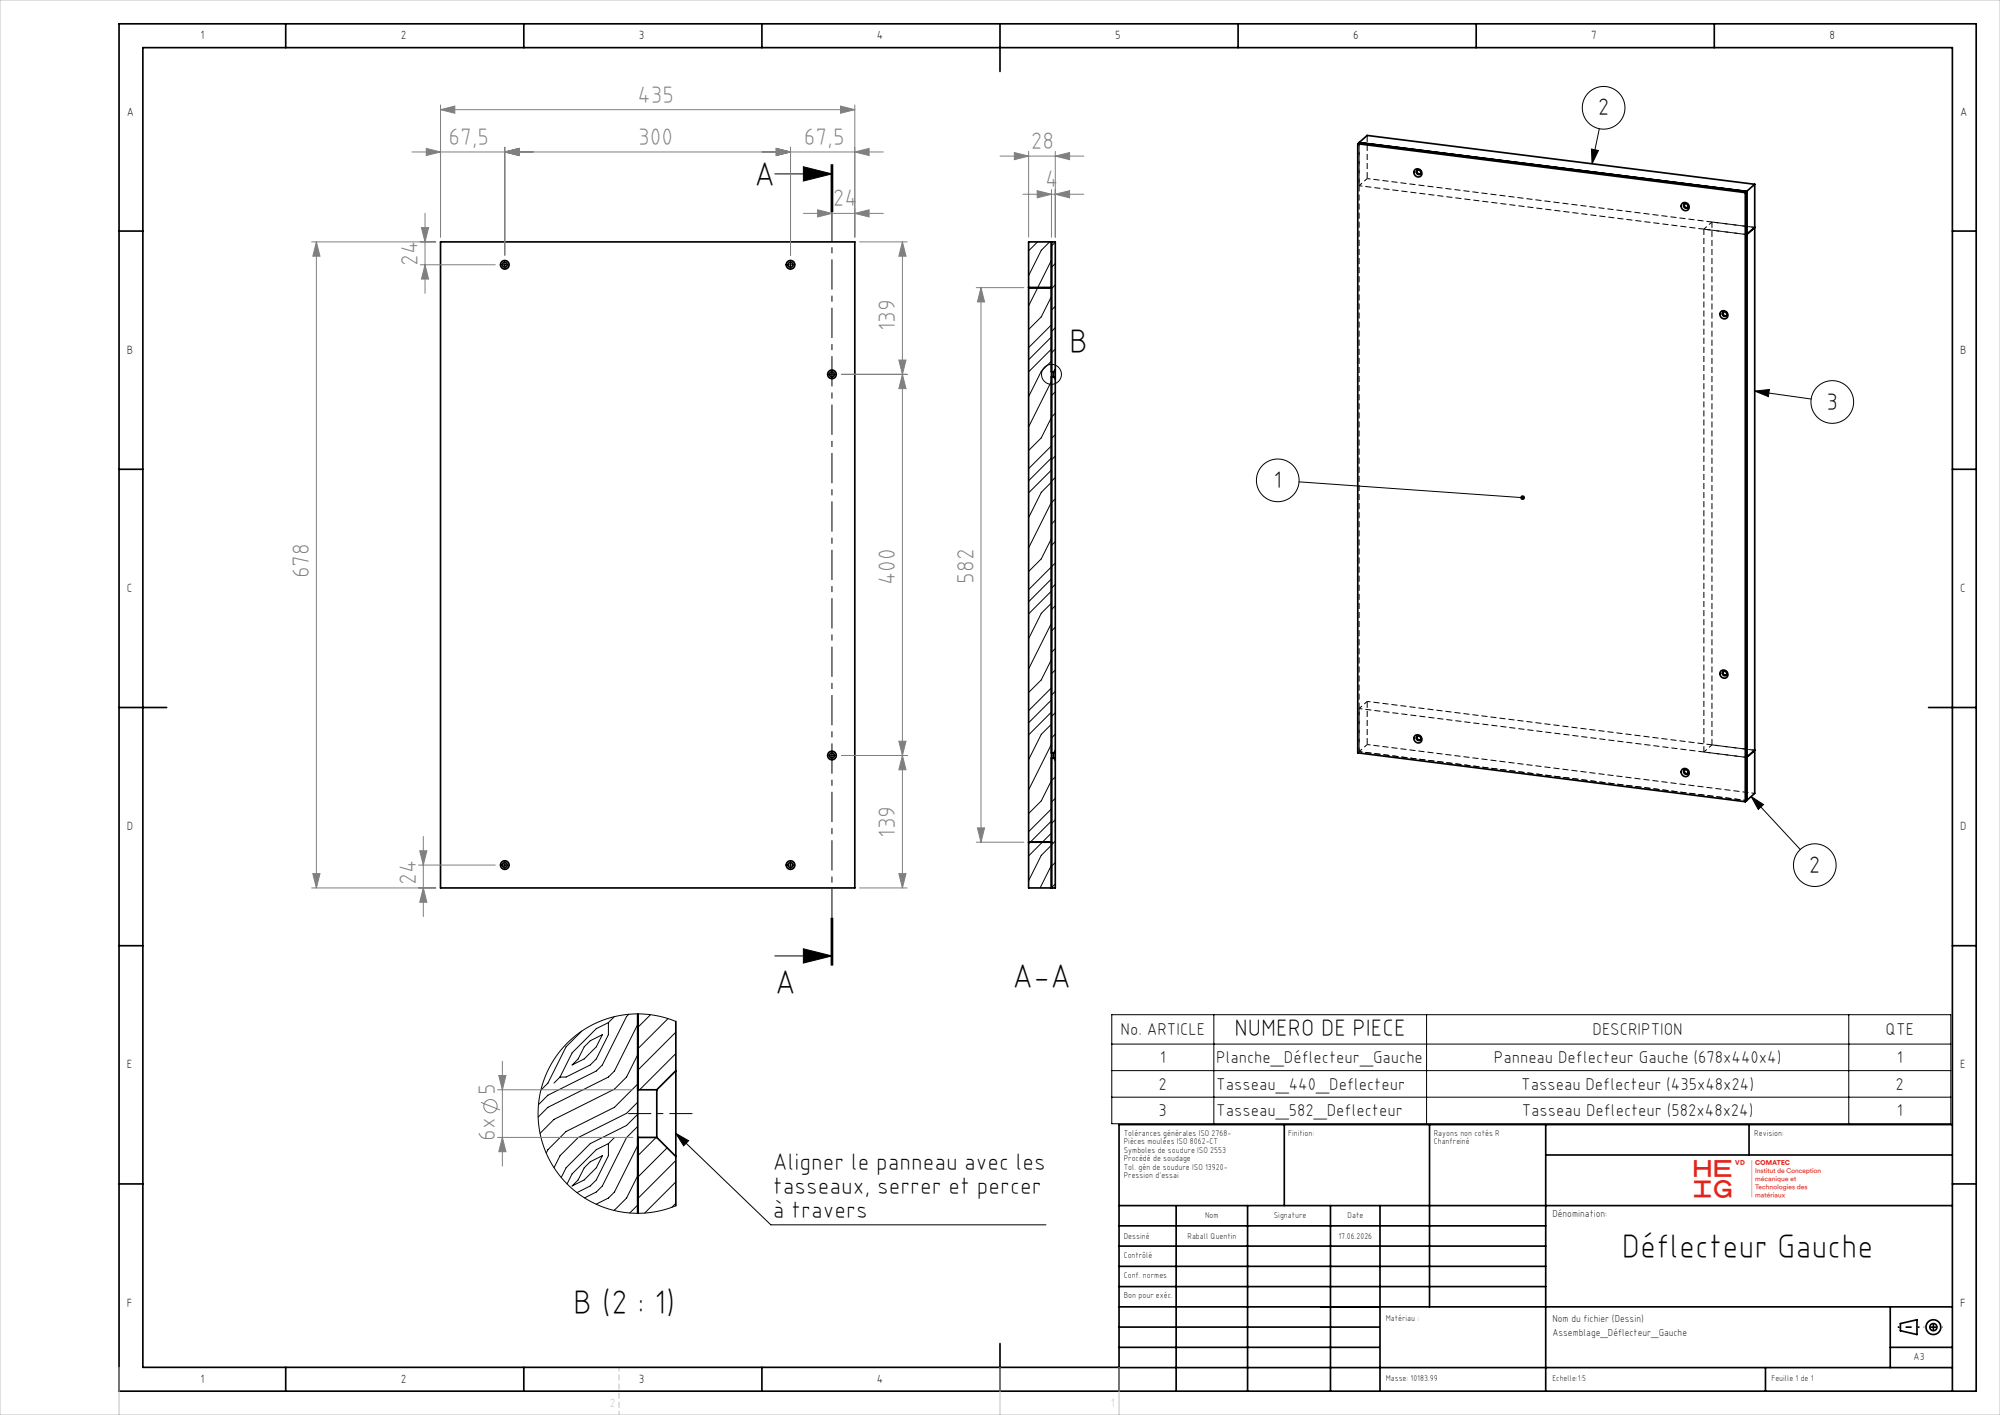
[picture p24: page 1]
Matériau :; Masse: 10183.99; Feuille 1 de 1; Raball Quentin; Déflecteur Gauche

No. ARTICLE | NUMERO DE PIECE | DESCRIPTION | QTE
1 | Planche_Déflecteur_Gauche | Panneau Deflecteur Gauche (678x440x4) | 1
2 | Tasseau_440_Deflecteur | Tasseau Deflecteur (435x48x24) | 2
3 | Tasseau_582_Deflecteur | Tasseau Deflecteur (582x48x24) | 1

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

Rayons non cotés R
Chanfreiné

Aligner le panneau avec les
tasseaux, serrer et percer
à travers

Dessiné
Contrôlé
Conf. normes
Bon pour exéc.

Nom du fichier (Dessin)
Assemblage_Déflecteur_Gauche

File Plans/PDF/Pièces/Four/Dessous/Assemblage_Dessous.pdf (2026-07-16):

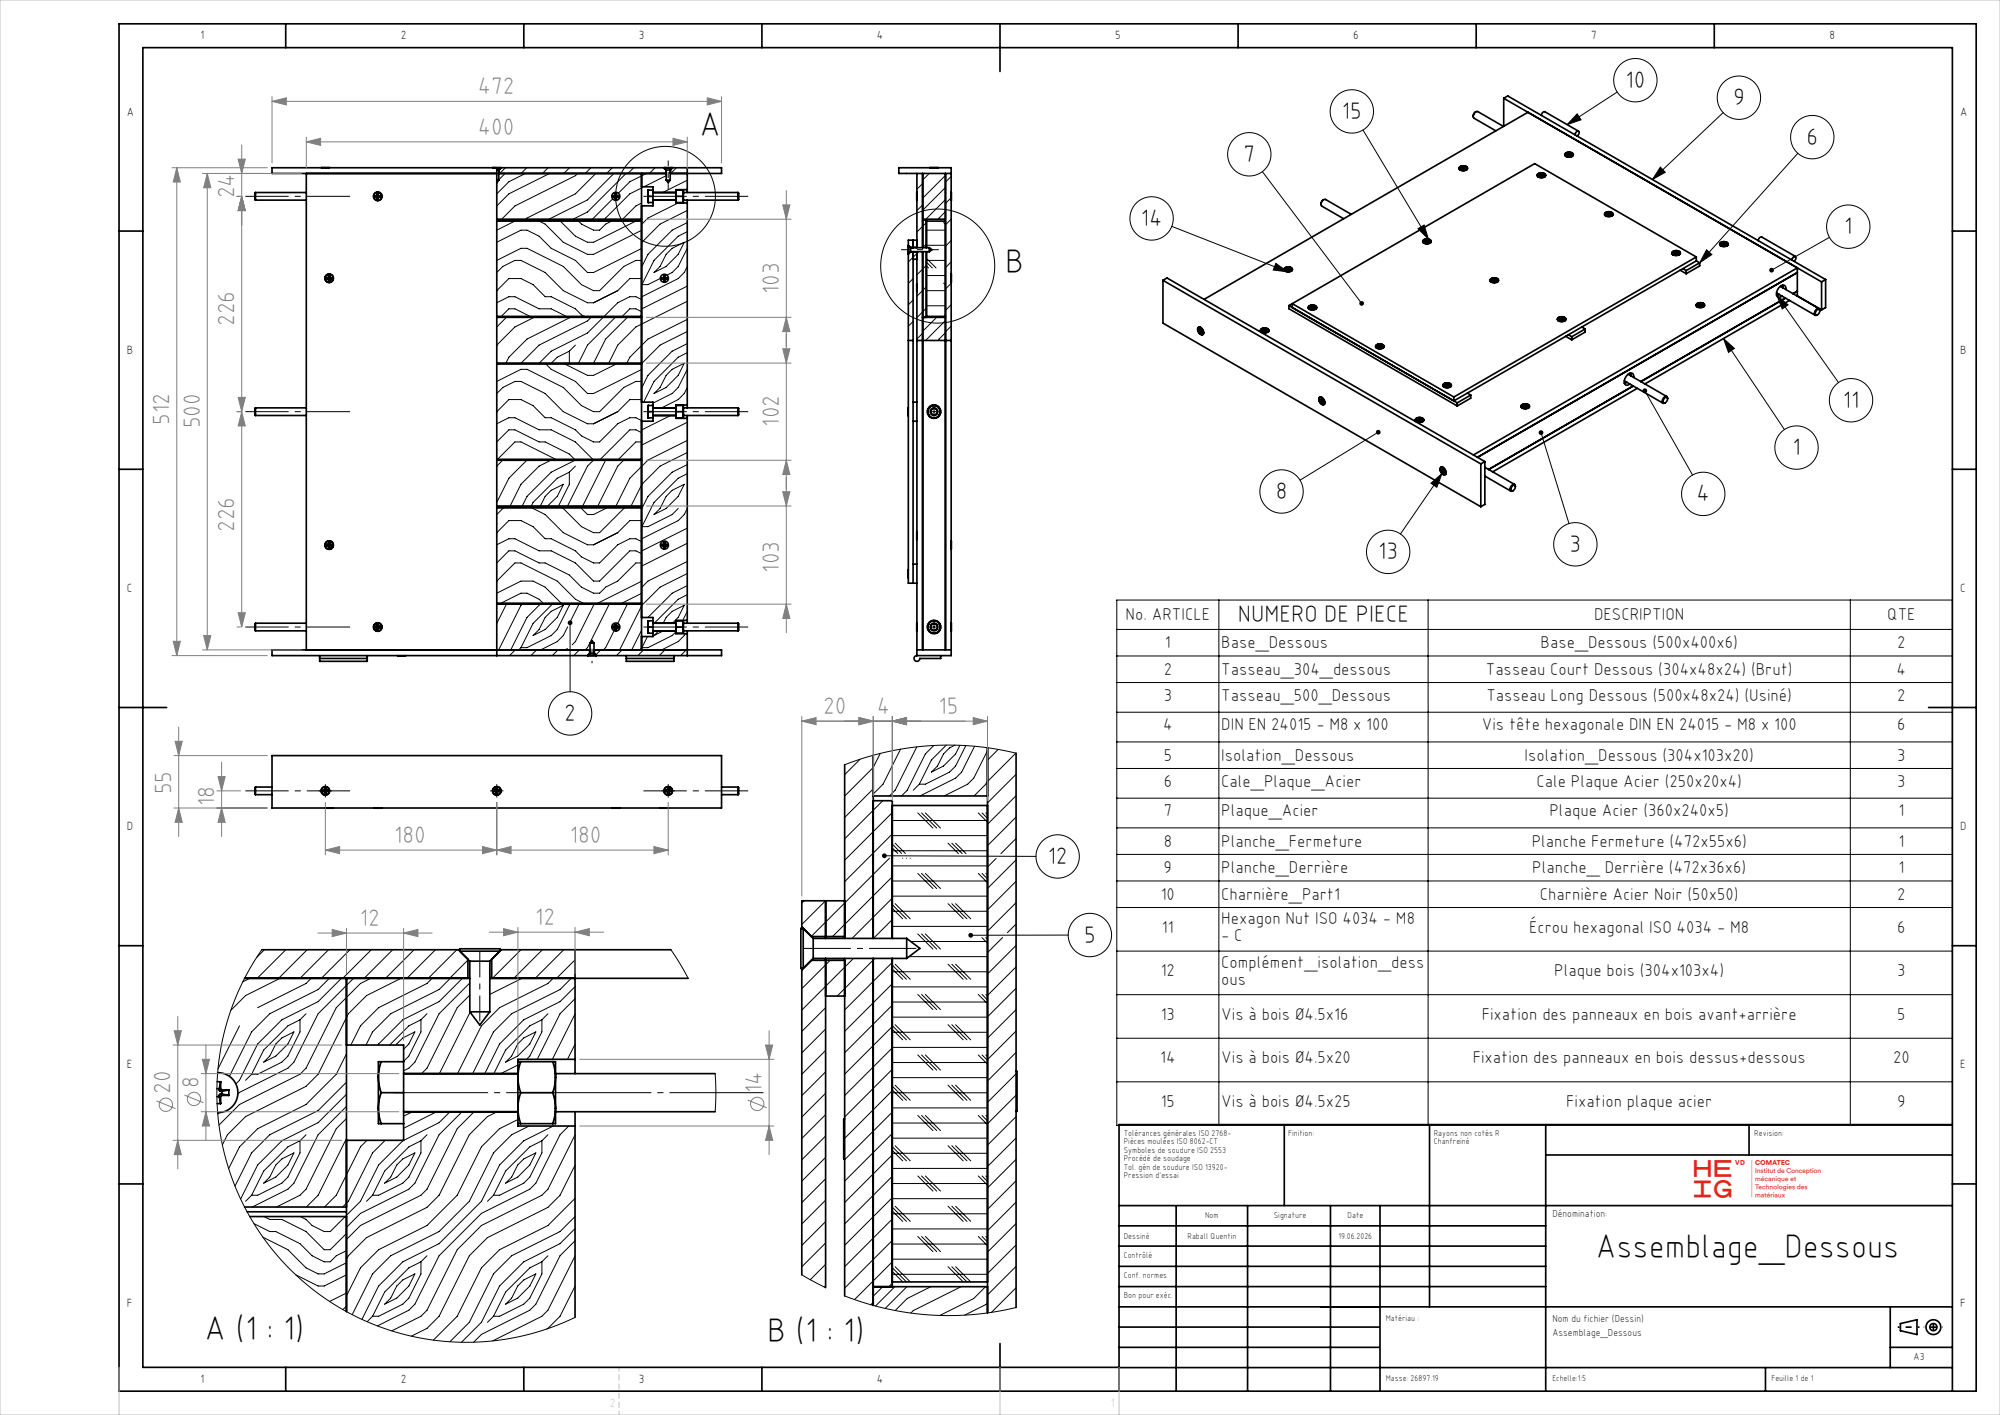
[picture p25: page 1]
Matériau :; Masse: 26897.19; Feuille 1 de 1; Raball Quentin

No. ARTICLE | NUMERO DE PIECE | DESCRIPTION | QTE
1 | Base_Dessous | Base_Dessous (500x400x6) | 2
2 | Tasseau_304_dessous | Tasseau Court Dessous (304x48x24) (Brut) | 4
3 | Tasseau_500_Dessous | Tasseau Long Dessous (500x48x24) (Usiné) | 2
4 | DIN EN 24015 - M8 x 100 | Vis tête hexagonale DIN EN 24015 - M8 x 100 | 6
5 | Isolation_Dessous | Isolation_Dessous (304x103x20) | 3
6 | Cale_Plaque_Acier | Cale Plaque Acier (250x20x4) | 3
7 | Plaque_Acier | Plaque Acier (360x240x5) | 1
8 | Planche_Fermeture | Planche Fermeture (472x55x6) | 1
9 | Planche_Derrière | Planche_ Derrière (472x36x6) | 1
10 | Charnière_Part1 | Charnière Acier Noir (50x50) | 2
11 | Hexagon Nut ISO 4034 - M8 - C | Écrou hexagonal ISO 4034 - M8 | 6

12 | Complément_isolation_dess ous | Plaque bois (304x103x4) | 3

13 | Vis à bois Ø4.5x16 | Fixation des panneaux en bois avant+arrière | 5

14 | Vis à bois Ø4.5x20 | Fixation des panneaux en bois dessus+dessous | 20

15 | Vis à bois Ø4.5x25 | Fixation plaque acier | 9

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

Rayons non cotés R
Chanfreiné

Dessiné
Contrôlé
Conf. normes
Bon pour exéc.

Nom du fichier (Dessin)
Assemblage_Dessous

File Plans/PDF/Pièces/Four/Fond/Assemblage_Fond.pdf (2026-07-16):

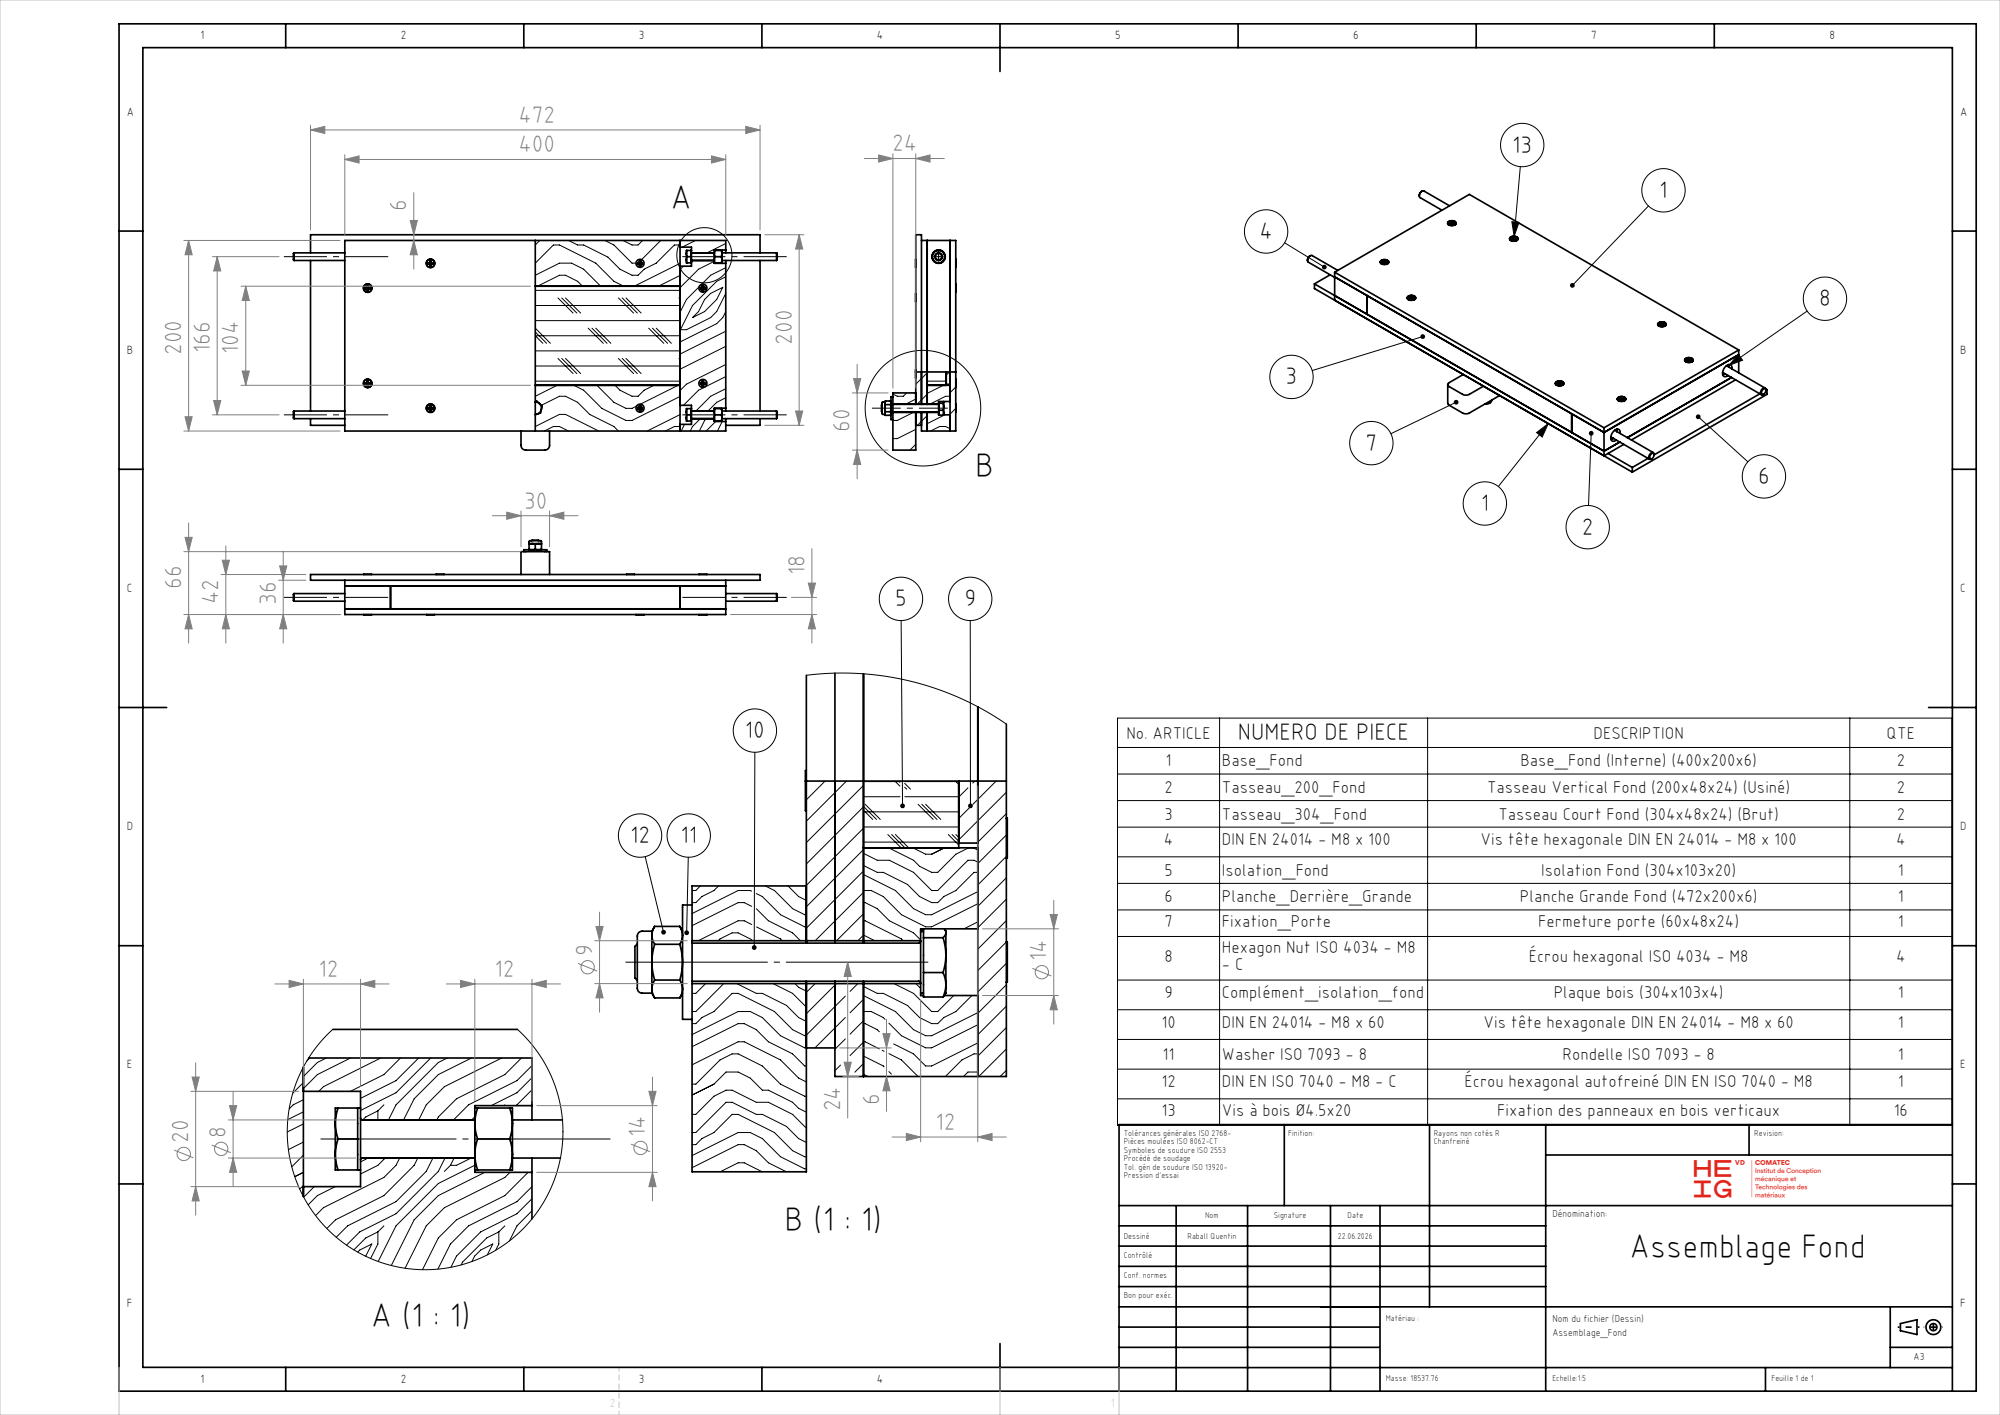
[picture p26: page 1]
Matériau :; Masse: 18537.76; Feuille 1 de 1; Raball Quentin; Assemblage Fond

No. ARTICLE | NUMERO DE PIECE | DESCRIPTION | QTE
1 | Base_Fond | Base_Fond (Interne) (400x200x6) | 2
2 | Tasseau_200_Fond | Tasseau Vertical Fond (200x48x24) (Usiné) | 2
3 | Tasseau_304_Fond | Tasseau Court Fond (304x48x24) (Brut) | 2
4 | DIN EN 24014 - M8 x 100 | Vis tête hexagonale DIN EN 24014 - M8 x 100 | 4
5 | Isolation_Fond | Isolation Fond (304x103x20) | 1
6 | Planche_Derrière_Grande | Planche Grande Fond (472x200x6) | 1
7 | Fixation_Porte | Fermeture porte (60x48x24) | 1
8 | Hexagon Nut ISO 4034 - M8 - C | Écrou hexagonal ISO 4034 - M8 | 4

9 | Complément_isolation_fond | Plaque bois (304x103x4) | 1
10 | DIN EN 24014 - M8 x 60 | Vis tête hexagonale DIN EN 24014 - M8 x 60 | 1
11 | Washer ISO 7093 - 8 | Rondelle ISO 7093 - 8 | 1
12 | DIN EN ISO 7040 - M8 - C | Écrou hexagonal autofreiné DIN EN ISO 7040 - M8 | 1
13 | Vis à bois Ø4.5x20 | Fixation des panneaux en bois verticaux | 16

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

Rayons non cotés R
Chanfreiné

Dessiné
Contrôlé
Conf. normes
Bon pour exéc.

Nom du fichier (Dessin)
Assemblage_Fond

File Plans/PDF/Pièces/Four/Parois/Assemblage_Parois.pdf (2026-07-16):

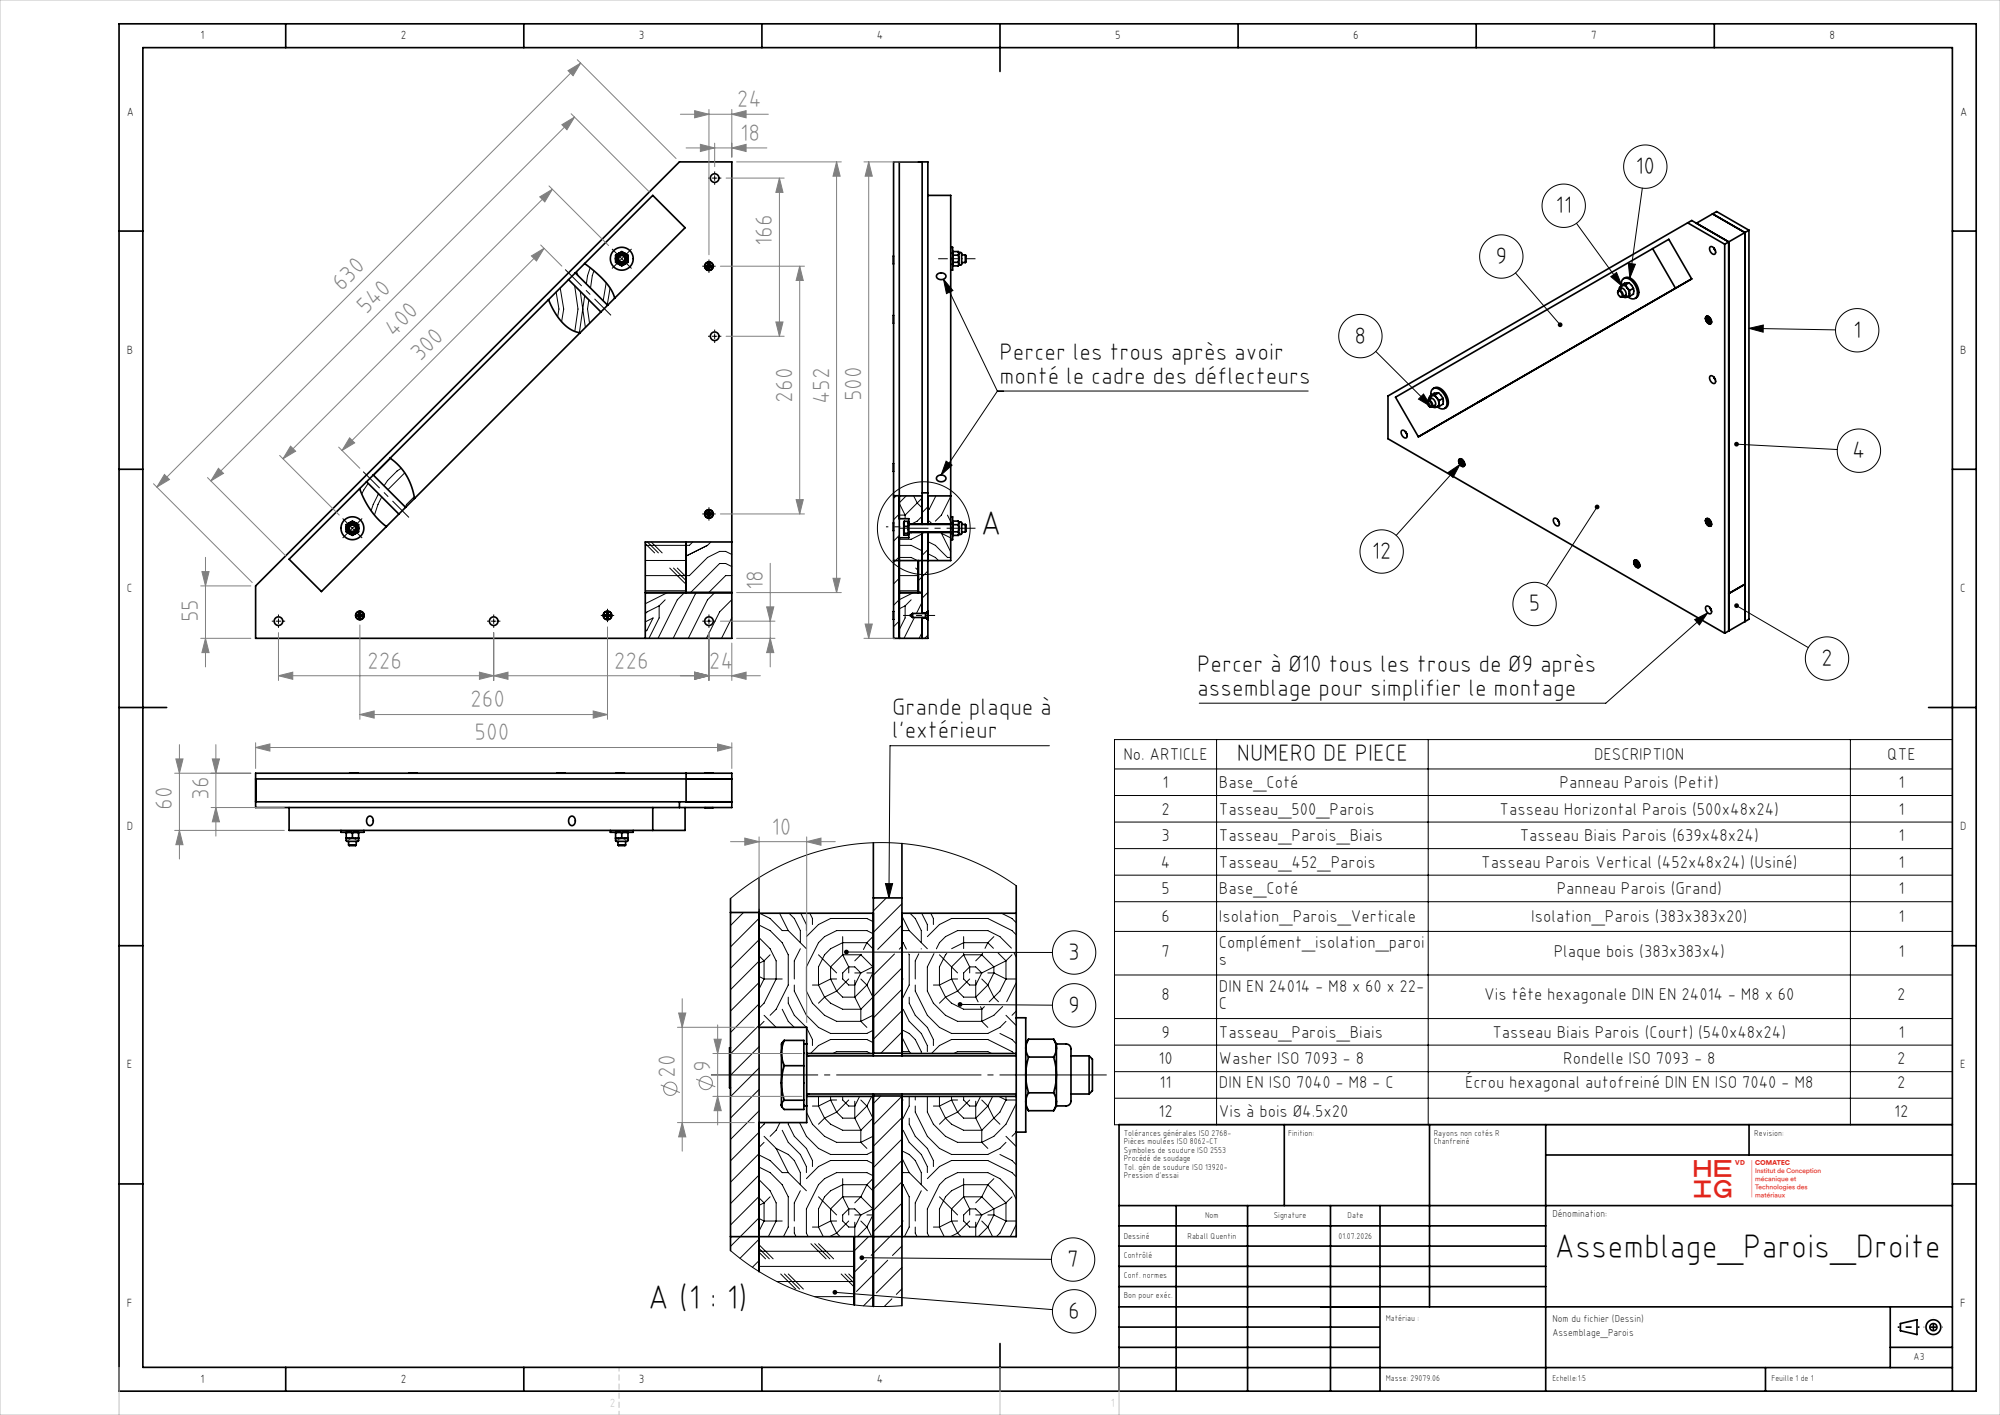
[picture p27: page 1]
Grande plaque à; Matériau :; Masse: 29079.06; Feuille 1 de 1; Raball Quentin

Percer les trous après avoir
monté le cadre des déflecteurs

Percer à Ø10 tous les trous de Ø9 après
assemblage pour simplifier le montage

No. ARTICLE | NUMERO DE PIECE | DESCRIPTION | QTE
1 | Base_Coté | Panneau Parois (Petit) | 1
2 | Tasseau_500_Parois | Tasseau Horizontal Parois (500x48x24) | 1
3 | Tasseau_Parois_Biais | Tasseau Biais Parois (639x48x24) | 1
4 | Tasseau_452_Parois | Tasseau Parois Vertical (452x48x24) (Usiné) | 1
5 | Base_Coté | Panneau Parois (Grand) | 1
6 | Isolation_Parois_Verticale | Isolation_Parois (383x383x20) | 1
7 | Complément_isolation_paroi s | Plaque bois (383x383x4) | 1

8 | DIN EN 24014 - M8 x 60 x 22-C | Vis tête hexagonale DIN EN 24014 - M8 x 60 | 2

9 | Tasseau_Parois_Biais | Tasseau Biais Parois (Court) (540x48x24) | 1
10 | Washer ISO 7093 - 8 | Rondelle ISO 7093 - 8 | 2
11 | DIN EN ISO 7040 - M8 - C | Écrou hexagonal autofreiné DIN EN ISO 7040 - M8 | 2
12 | Vis à bois Ø4.5x20 | | 12

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

Rayons non cotés R
Chanfreiné

Contrôlé
Conf. normes
Bon pour exéc.

Nom du fichier (Dessin)
Assemblage_Parois

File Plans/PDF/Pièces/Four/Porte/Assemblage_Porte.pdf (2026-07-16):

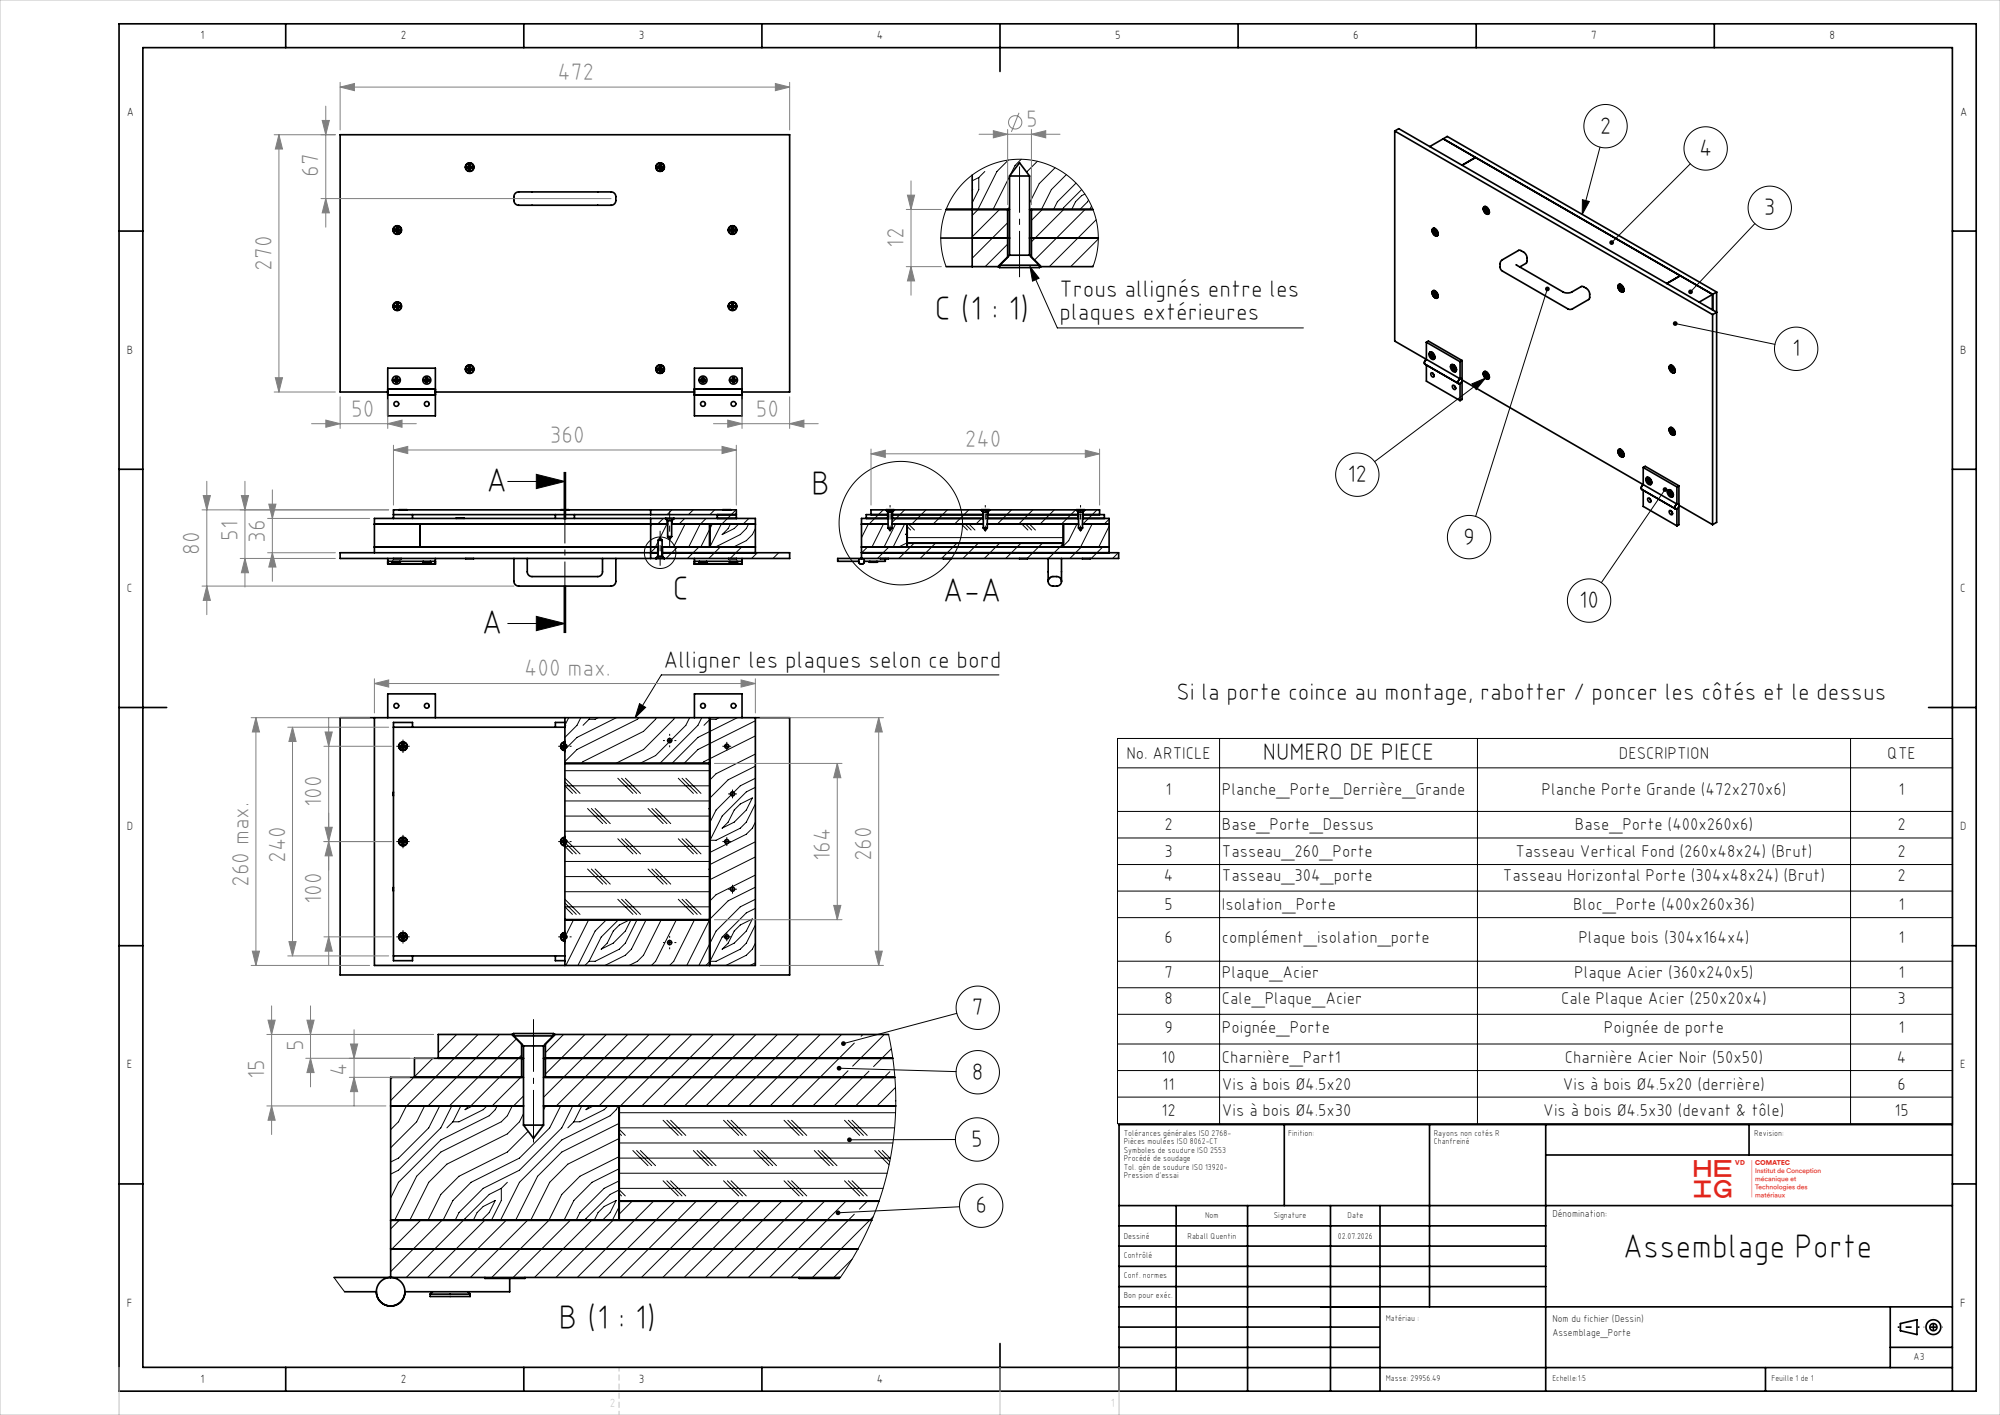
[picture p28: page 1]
260 max.; 400 max.; plaques extérieures; Matériau :; Masse: 29956.49; Feuille 1 de 1; Raball Quentin; Assemblage Porte

C (1 : 1) Trous allignés entre les

Alligner les plaques selon ce bord

Si la porte coince au montage, rabotter / poncer les côtés et le dessus

No. ARTICLE | NUMERO DE PIECE | DESCRIPTION | QTE

1 | Planche_Porte_Derrière_Grande | Planche Porte Grande (472x270x6) | 1
2 | Base_Porte_Dessus | Base_Porte (400x260x6) | 2
3 | Tasseau_260_Porte | Tasseau Vertical Fond (260x48x24) (Brut) | 2
4 | Tasseau_304_porte | Tasseau Horizontal Porte (304x48x24) (Brut) | 2
5 | Isolation_Porte | Bloc_Porte (400x260x36) | 1
6 | complément_isolation_porte | Plaque bois (304x164x4) | 1
7 | Plaque_Acier | Plaque Acier (360x240x5) | 1
8 | Cale_Plaque_Acier | Cale Plaque Acier (250x20x4) | 3
9 | Poignée_Porte | Poignée de porte | 1
10 | Charnière_Part1 | Charnière Acier Noir (50x50) | 4
11 | Vis à bois Ø4.5x20 | Vis à bois Ø4.5x20 (derrière) | 6
12 | Vis à bois Ø4.5x30 | Vis à bois Ø4.5x30 (devant & tôle) | 15

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

Rayons non cotés R
Chanfreiné

Dessiné
Contrôlé
Conf. normes
Bon pour exéc.

Nom du fichier (Dessin)
Assemblage_Porte

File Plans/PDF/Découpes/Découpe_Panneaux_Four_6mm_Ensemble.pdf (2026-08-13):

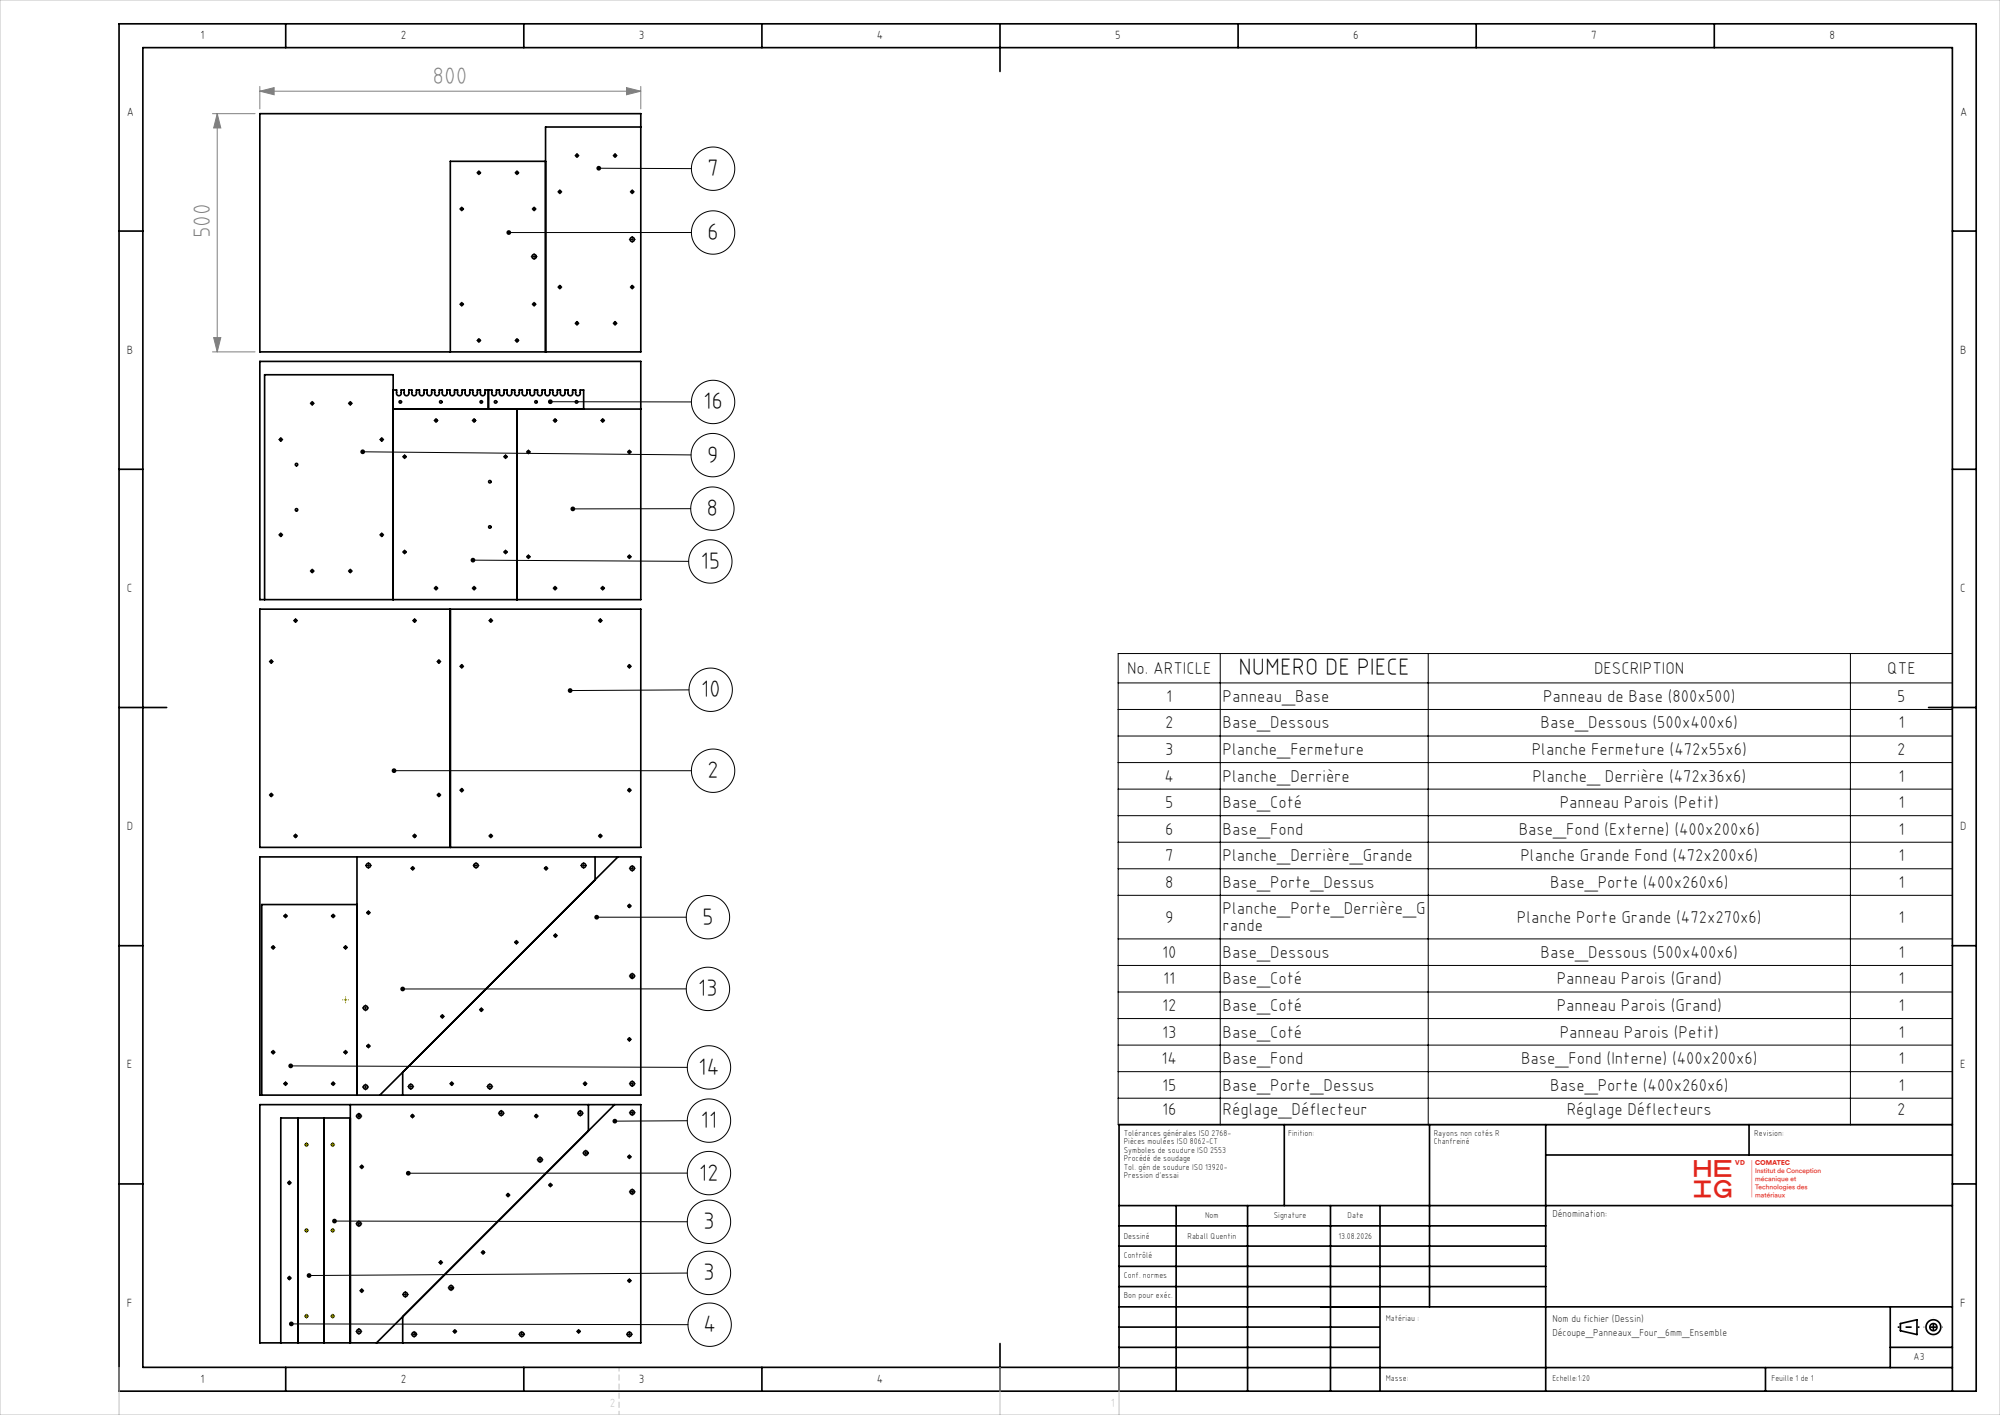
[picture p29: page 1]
No. ARTICLE; NUMERO DE PIECE; DESCRIPTION; QTE 1; Panneau_Base; Panneau de Base (800x500); Base_Dessous; Base_Dessous (500x400x6); Planche_Fermeture; Planche Fermeture (472x55x6); Planche_Derrière; Planche_ Derrière (472x36x6); Base_Coté; Panneau Parois (Petit); Base_Fond; Base_Fond (Externe) (400x200x6); Planche_Derrière_Grande; Planche Grande Fond (472x200x6); Base_Porte_Dessus; Base_Porte (400x260x6); Planche_Porte_Derrière_G; Matériau :; Feuille 1 de 1; Raball Quentin

rande | Planche Porte Grande (472x270x6) | 1
10 | Base_Dessous | Base_Dessous (500x400x6) | 1
11 | Base_Coté | Panneau Parois (Grand) | 1
12 | Base_Coté | Panneau Parois (Grand) | 1
13 | Base_Coté | Panneau Parois (Petit) | 1
14 | Base_Fond | Base_Fond (Interne) (400x200x6) | 1
15 | Base_Porte_Dessus | Base_Porte (400x260x6) | 1
16 | Réglage_Déflecteur | Réglage Déflecteurs | 2

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

Rayons non cotés R
Chanfreiné

Dessiné
Contrôlé
Conf. normes
Bon pour exéc.

Nom du fichier (Dessin)
Découpe_Panneaux_Four_6mm_Ensemble

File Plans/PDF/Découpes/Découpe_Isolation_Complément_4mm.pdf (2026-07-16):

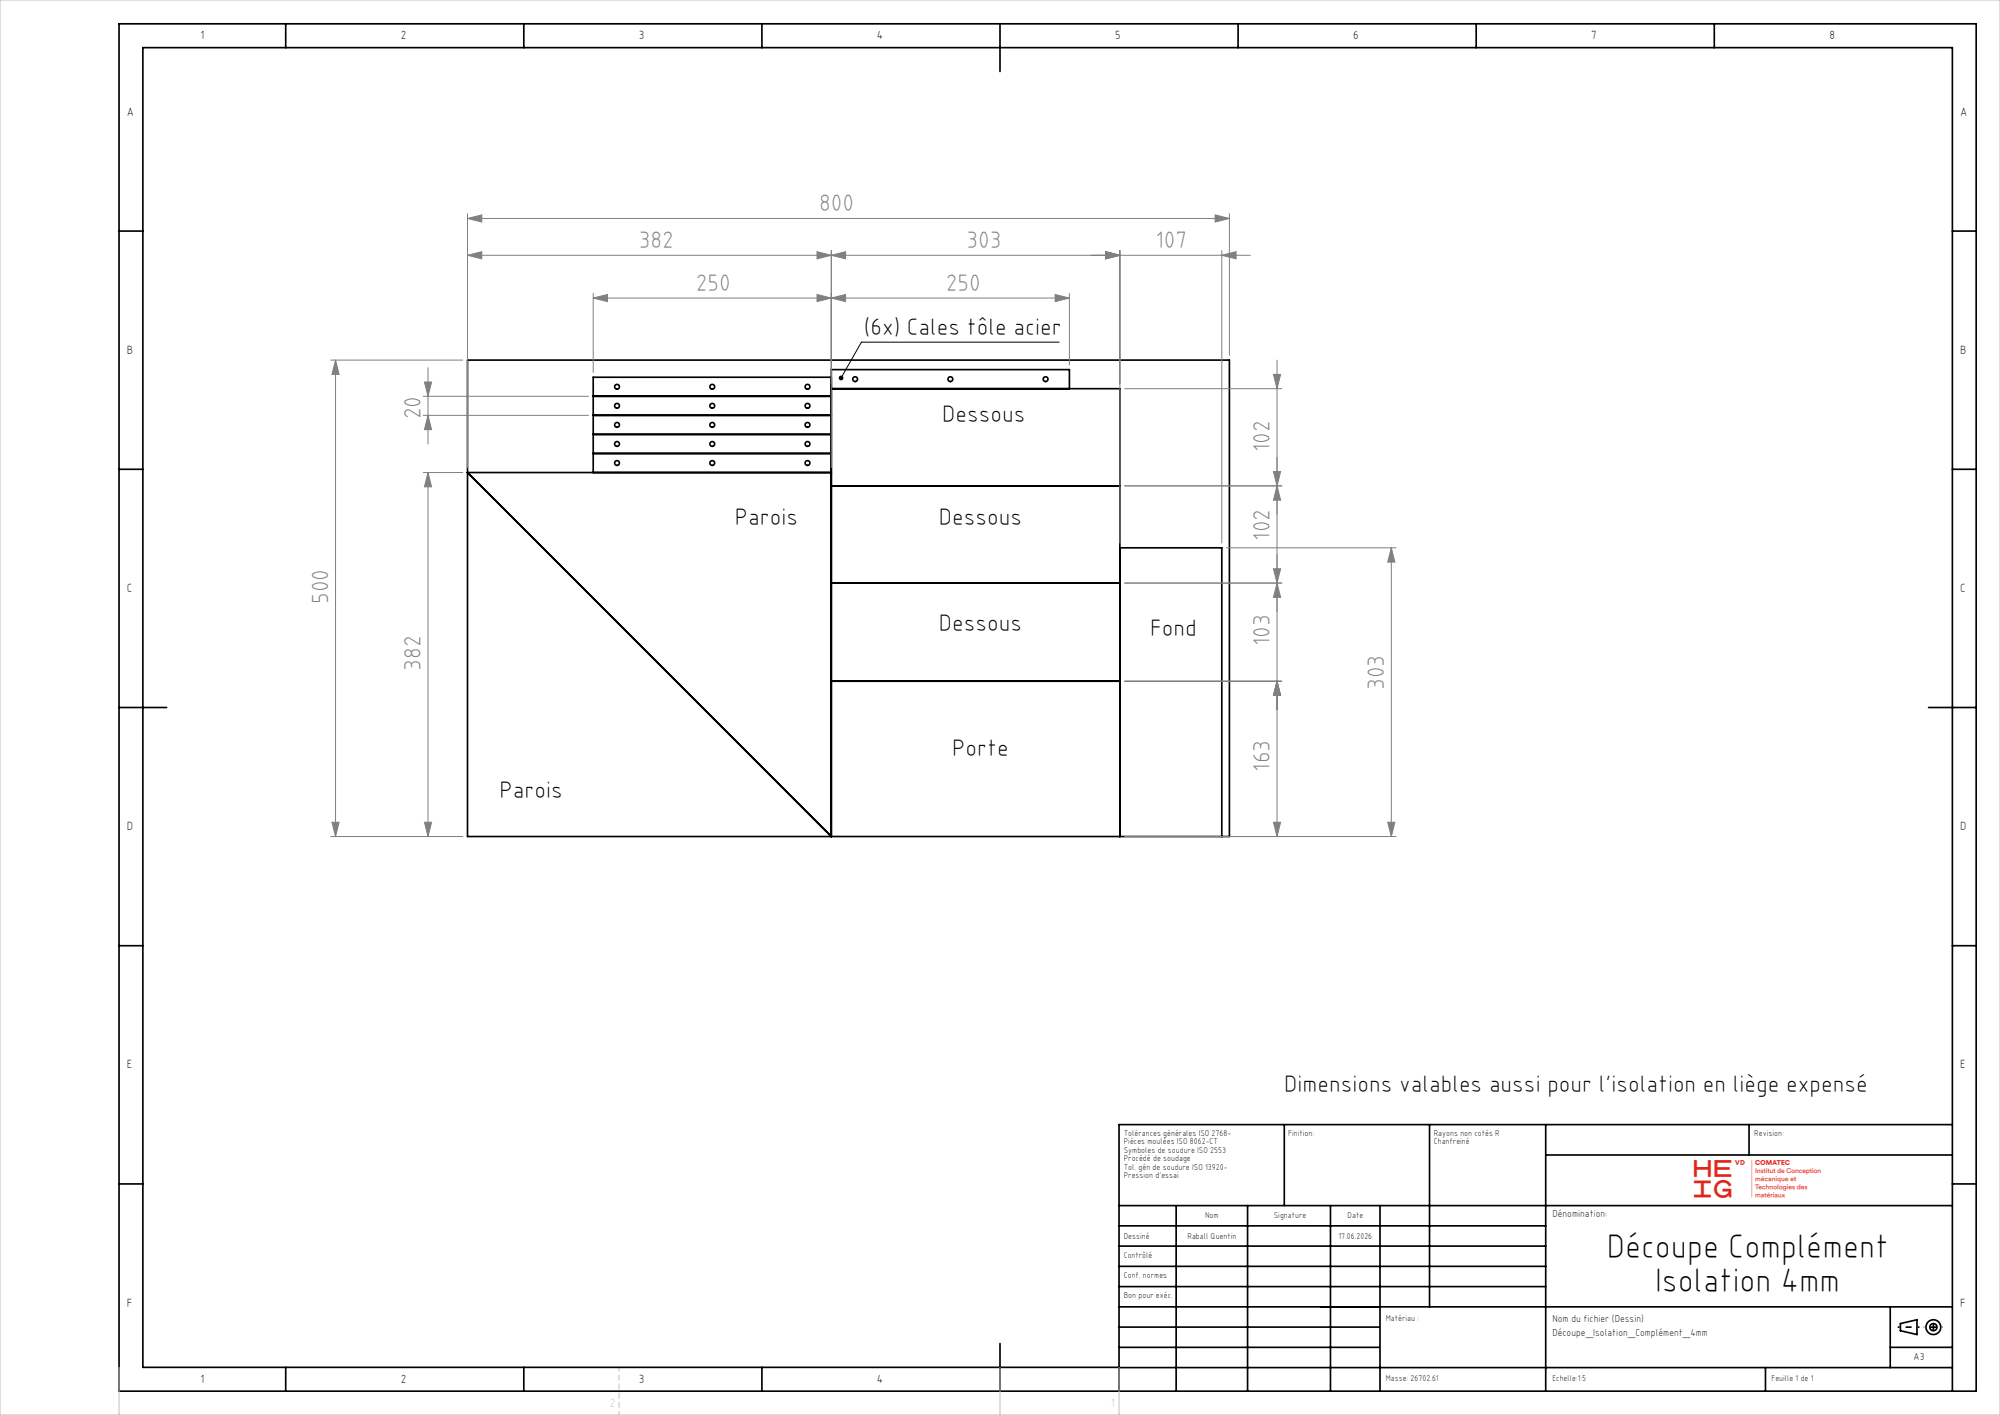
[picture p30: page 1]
Matériau :; Masse: 26702.61; Feuille 1 de 1; Raball Quentin; Découpe Complément Isolation 4mm

(6x) Cales tôle acier

Dimensions valables aussi pour l'isolation en liège expensé

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

Rayons non cotés R
Chanfreiné

Dessiné
Contrôlé
Conf. normes
Bon pour exéc.

Nom du fichier (Dessin)
Découpe_Isolation_Complément_4mm

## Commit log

2026-07-16 Premiers ajouts
    [Adaptateur_Charnière.SLDPRT, Adaptateur_Charnière.STEP, Assemblage_Dessous.SLDASM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]
2026-08-04 Modification stucture dossier
    [Adaptateur_Charnière.SLDPRT, Adaptateur_Charnière.STEP, Assemblage_Dessous.SLDASM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]
2026-08-07 Ajout de quelques images du montage
    [Assemblage_Déflecteurs_MOD.SLDASM, Assemblage_Fond.SLDASM, Assemblage_Four_Deflecteur.SLDASM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]
2026-08-07 Ajout configuration et changement fixation déflecteur haut
    [Assemblage_Déflecteur_Haut.SLDASM, Assemblage_Déflecteurs_MOD.SLDASM, Assemblage_Fond.SLDASM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]
2026-08-12 Modification conf et ajout photo
    [Retour d'expérience.xlsx]
2026-08-13 Ajout cale de réglage au fichiers de découpe
    [Assemblage_Déflecteur_Haut.SLDASM, Assemblage_Déflecteurs_MOD.SLDASM, Découpe_6mm.SLDASM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]
2026-08-13 Update README.md
    Ajout de remarques supplémentaires
2026-08-13 Ajout du document sur le choix des matériaux
2026-08-19 Premiers essais sous le soleil
    [Retour d'expérience.xlsx]
2026-08-20 Ajout de retours d'exp (REX)
    [Complement.DXF, Plaque_6mm_Parois.SLDDRW, Retour d'expérience.xlsx]
